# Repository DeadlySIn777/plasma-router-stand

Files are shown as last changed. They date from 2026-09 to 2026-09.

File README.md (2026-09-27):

# Plasma / router CNC stand

Public working design for **800 mm X / 1000 mm Y / 100 mm Z nominal travel**.

**Preserved baseline: Rev I.** It adds a floating/breakaway head mechanism,
stronger storage restraints, supported plumbing and defined water/tool control
circuits. It is still an engineering design with open measured interfaces and
integration work, **not a fabrication-ready or operational machine**.

**Latest design work:** [retractable ATC mechanisms for both machines](variants/retractable-atc/README.md),
with 200 mm slide travel, automatic pin release and onboard Kraken drive
allocations. The small-machine proposal includes a longer Z configuration;
the 4x8 uses a separate side bay. These have their own CAD, controls model and
checks. Exact magazine interfaces and machine qualification remain open.
Use the [variant index](variants/README.md) to distinguish these proposals from
the preserved Rev I baseline and earlier fixed-dock studies.

## Open the current design

- [Latest small and 4x8 retractable ATC work](variants/retractable-atc/README.md)
- [Baseline Rev I CAD package and limitations](output/release-review/RevI-CAD/README.md)
- [Baseline router assembly STEP](output/release-review/RevI-CAD/step/RevI_ROUTER.step)
- [Baseline bed stored assembly STEP](output/release-review/RevI-CAD/step/RevI_BED_STORED.step)
- [Plasma head hardware STEP](output/release-review/RevI-CAD/step/RevI_PLASMA_HARDWARE.step) — measured torch not yet installed
- [Updated concept PDF](output/pdf/plasma-router-stand-concept.pdf)
- [Changes, evidence and reproduction](output/design-finish-2026-09-26/README.md)
- [Current verification index](output/design-finish-2026-09-26/ACCEPTANCE.md)
- [Every original audit finding](output/design-finish-2026-09-26/FINDING-DISPOSITION.md)
- [Remaining engineering and measured inputs](output/design-finish-2026-09-26/OPEN-ITEMS.md)
- [Mechanical component schedule](output/release-review/RevI-CAD/cutlist.csv)
- [Selected controls schedule](output/design-finish-2026-09-26/controls/selected-components.json)
- [Scrap tube lengths and inspection inputs](output/design-completion-2026-09-26/SCRAP-TUBE-GUIDE.md)
- [X/Y lead check and arrival measurements](output/design-completion-2026-09-26/CONTROL-SCALE-CHECK.md)

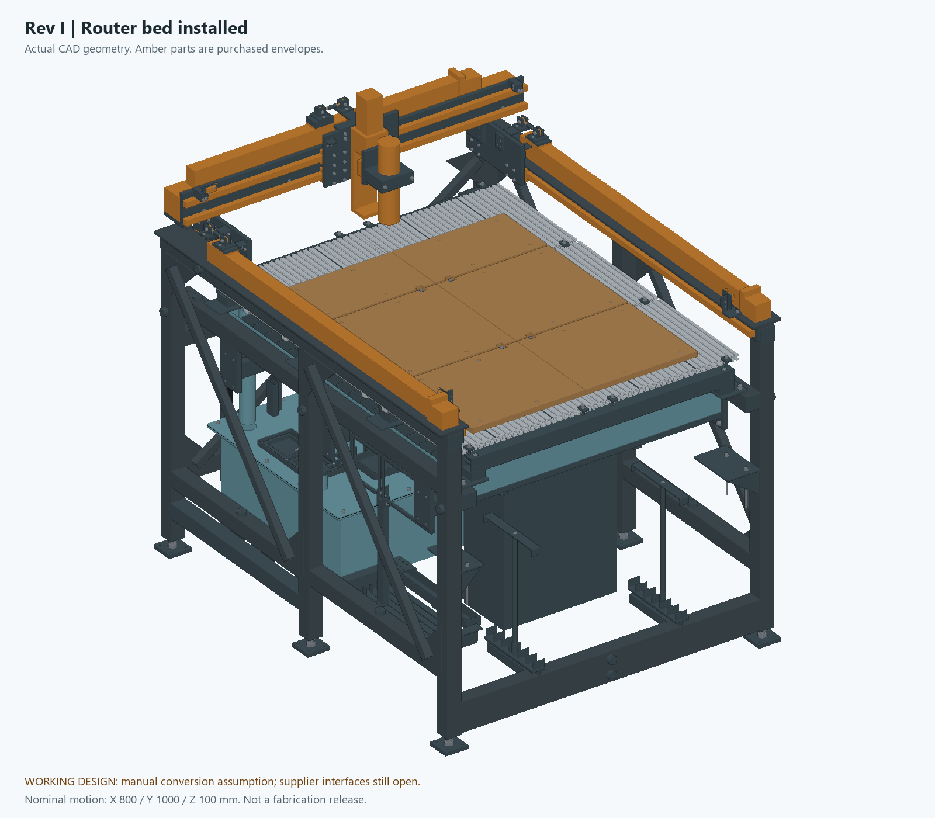
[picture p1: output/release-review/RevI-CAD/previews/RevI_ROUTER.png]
Preserved Rev I router baseline


The view above is the Rev I baseline. The [latest retractable ATC package](variants/retractable-atc/README.md) contains the new small and full-sheet machine views and STEP files.

## Design and changes

Ten 1220 mm extrusion bars yield thirty 397 mm strips in six 500 × 397 mm
panels. The bare bed is 1003 × 1211 mm. Panels, four support beams and separate
spoilboards store inside the chassis. Conversion is manual and retains 52
primary release fasteners plus restraint/tool operations. It is not an
automatic or quick bed changer.

The head now has twin guides, 6 mm captured float, cone/V/flat magnetic release,
sealed detection switches, machined clamp features and internal parking. Its
replaceable insert remains unbored until the actual torch is measured. The
plasma hardware view is therefore a mechanism assembly, not an invented
ready-to-cut VIV ARC CUT-50 setup.

Storage rods increase from 10 to 14 mm with 40 mm sockets and thicker seats.
Actual-section calculations replace the earlier incomplete stiffness claim.
The proposed light-routing target is 0.20 mm tool-to-work displacement at
100 N; known bed members alone account for about 0.135 mm. Actual motion,
mount, joint and tool compliance remain unqualified. Sand receives no
elastic-stiffness credit.

The water system gains a supported drain/flange, removable tail and parking
cup, strainer carrier, corrected pump orientation and supported pressure and
suction hose routes. The reservoir stays vented. A compressor or venturi is
not connected to the fabricated tank.

[Current controls](output/design-finish-2026-09-26/controls/README.md) retain
Kraken V1.1 with onboard drivers. Actual terminal circuits, timer contacts,
isolated run request, restart prevention and a selected C41S speed converter
are defined. Separate [isolated head inputs](output/design-finish-2026-09-26/controls/HEAD-INTERFACE.md)
connect the float and breakaway switches. Router Z zero remains manual; the
parked plasma float is not a spindle touchplate. The populated panel, complete stop/power/brake system, actual
VFD/cutter interface and physical commissioning remain unfinished.

The selected X/Y catalog variants specify **10 mm lead**, meaning movement
per screw revolution, not screw diameter. The selected SFU1605 Z has 5 mm
lead. Verify delivered modules before final calibration and adapter drilling.

The 2 × 2 tube list remains 30 blanks totaling 29,472 mm / 96.69 ft net, using
3.048 mm modeled wall. Actual scrap lengths, remaining wall and condition
must be recorded before nesting. The mechanical cut list is not a complete
electrical BOM or a current delivered purchase total.

## Evidence, history and cost

The [verification index](output/design-finish-2026-09-26/ACCEPTANCE.md) binds
current assembly, pose, route, service, mechanism, circuit and export reports
to their source files. These checks have explicit limits: nominal clear
geometry does not establish physical rigidity, force thresholds, operator
access, live electrical behavior or machining accuracy.

The active generator is [build_revi.py](output/release-review/RevE-ENGINEERING/build_revi.py).
Shared Python sources retain their legacy directory name; **current exports
are in RevI-CAD**. Rev H, Rev G, older exports and the
[29-finding audit](output/cad-reaudit-2026-09-25/README.md) are preserved as
historical evidence. They are not relabeled as current results.

[Earlier prices](outputs/reve-30510/CNC-plasma-RevE-budget.xlsx) and the
[actual-price audit](outputs/reve-30510/actual-cost/REAL-COST.md) are historical
procurement research. Quantities changed; neither is a complete Rev I build
total. No purchase, vendor message, firmware flash or machine operation is
implied by this public design record.

CadQuery/OpenCascade generate exchange geometry; ReportLab generates the
concept brief. This is not a native Fusion feature-history or machine-specific
CAM release. The [original snapshot manifest](REPOSITORY-SNAPSHOT.json)
describes the initial import only. Supplier material retains its existing
license notices; this repository grants no new rights over it.

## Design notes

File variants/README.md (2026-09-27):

# Small ATC and full-sheet 4x8 variants

Two development variants extend the [existing Rev I small machine](../output/release-review/RevI-CAD/README.md).
The requested ATC, repeatable removable table interfaces and second full-sheet
machine are now separate design work. Rev I remains the small-machine baseline;
its existing checks do not automatically qualify these additions.

| Design | Working area / stock | Bed and ATC arrangement |
|---|---|---|
| [Small retractable ATC](retractable-atc/small-mechanism/README.md) | Targets existing 800 X × 1000 Y; proposed 200 Z configuration, separately from baseline 100 Z | Raised open carrier, guided rearward parking, automatic spring-pin release; exact loaded magazine remains to fit |
| [Full-sheet retractable ATC](retractable-atc/large-mechanism/README.md) | 1219.2 × 2438.4 mm stock; additional deck-surfacing travel | Separate dry side bay, 200 mm slide and guided outer shutter; based on the [4x8 development frame](48x96/README.md) |
| [Shared locating interfaces](common/location/README.md) | Metal datum chain, independently checked fits and thermal allowances | Round pin + diamond pin, replaceable metal bushings, hard Z seats and separate clamps |

**Latest package:** [retractable ATC on both machines](retractable-atc/README.md),
with a 200 mm useful-stroke target, detailed mechanism candidates and an offline
interlock model. The earlier [fixed small dock](small-atc/README.md) and first
packaging studies remain historical candidates. They are not the newest ATC
assembly and do not share the revised clearance result.

The large dimensions assume 4x8 means usable sheet size. ATC on both machines is
now requested; the exact kit remains unconfirmed. The [requirements record](requirements.json) distinguishes requests,
working assumptions and open inputs.

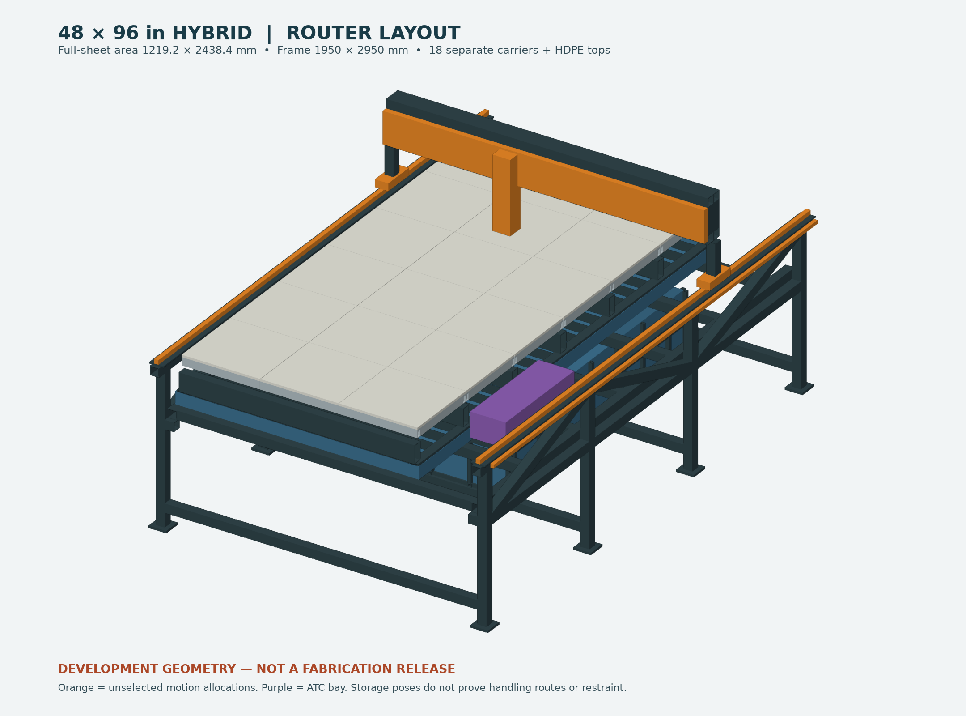
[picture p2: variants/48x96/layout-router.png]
Full-sheet machine development layout


The image above shows the underlying 4x8 frame layout. Current ATC mechanism
views and exchange files are linked from the latest package.

## Repeatable removal

Locate each metal carrier with one round pin and one relieved/diamond pin.
The first fixes two horizontal directions; the second fixes rotation without
forcing a second fully constrained hole spacing. Three hard seats define the
height plane. Supplementary supports must be fitted to that plane, and separate
clamps provide hold-down. Precision pins are not pressed into HDPE.

The HDPE top is a wear layer attached with room for thermal movement and metal
compression limiters. Its expansion must not move the carrier's locating
features. Each reinstallation requires clean datums, correct seating, clamping
and a reference check. Numerical return targets in the common interface are
acceptance targets, not demonstrated machine accuracy.

The common locator assembly is modeled separately. Its integration into the
small table and all 18 large carriers remains open; the table models do not yet
contain the completed pin, clamp and thermal-clearance details.

## ATC is more than a magazine

The [retractable mechanism controls](retractable-atc/controls/README.md) extend
the earlier [ATC interface reservations](common/controls/ATC-INTEGRATION.md)
with motor allocations, isolated position inputs, lock outputs and an executable
offline interlock model. This is not flashed machine firmware or calibrated M6.
The actual spindle/VFD must still support the required low-speed reverse cycle.

Manufacturer mounting geometry and the exact RapidChange kit are still required
to release the drilled adapter and pocket coordinates. Colored ATC allocations
in CAD represent reserved space, not a supplier-certified magazine solid.
The earlier fixed small dock consumes part of its work area. Its retractable
successor adds vertical clearance and explicit stored-tool limits to address
that loss; the large machine reserves a side bay beyond the sheet. Removal must preserve or re-establish
the pocket reference before automatic changes resume.

The approximately **USD 700** kit figure is a user budget target. Official shop
pages currently present different prices/options. It is not a delivered quote
and excludes any unquoted freight, tax, extra tooling and interface parts.
The [kit comparison and manufacturer requirements](common/atc/README.md) record
the sourced prices and the exact dimensions that still need confirmation.

## Scope of this package

The links above include generated CAD, checks and explicit limits. The large
machine is a layout with unselected motion components and unfinished joint,
service and conversion details. The small dock is a candidate that requires the
actual kit and spindle dimensions. Neither is a fabrication or CAM release.

The existing [Rev I concept PDF](../output/pdf/plasma-router-stand-concept.pdf)
continues to describe the baseline small machine. It is not silently relabeled
as the new 4x8 or an ATC-qualified model. See the variant pages for new geometry.

The [package check](package-verification.json) binds the new reports and files
to their source and checks that the prior baseline remains unchanged. A PASS
there concerns the published evidence, not fabrication or machine operation.

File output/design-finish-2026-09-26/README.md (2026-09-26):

# Rev I design repairs — 26 September 2026

Rev I adds a guided floating/breakaway head, stronger storage restraints,
supported plumbing with service paths, and defined water/tool control circuits
to the frozen Rev H design. It is a working engineering package, **not a
finished fabrication or operating-machine release**.

The current [verification index](ACCEPTANCE.md) identifies the source-matching
reports. An intermediate report marked failed or stale is diagnostic history,
not acceptance. Read the index before using counts or pass claims below.

## Current design

- [CAD package](../release-review/RevI-CAD/README.md), including router, stored-bed and plasma-head-hardware assemblies.
- [Updated concept PDF](../pdf/plasma-router-stand-concept.pdf).
- [Original findings and current disposition](FINDING-DISPOSITION.md).
- [Remaining engineering and measured inputs](OPEN-ITEMS.md).
- [Structural joints and load targets](structure/JOINTS.md).
- [Head mechanism, transfer sequence and limitations](motion/README.md).
- [Combined bed and tool conversion sequence](motion/CONVERSION-SEQUENCE.md).
- [Water/cabinet geometry and servicing](service/README.md).
- [Kraken control baseline and terminal circuits](controls/README.md).
- [Isolated float-probe and breakaway interfaces](controls/HEAD-INTERFACE.md).
- [Current part inventory and material layouts](../release-review/RevI-CAD/cutlist.csv).
- [Arrival measurement worksheet](../design-completion-2026-09-26/motion/ARRIVAL-MEASUREMENTS.md) and [scrap tube guide](../design-completion-2026-09-26/SCRAP-TUBE-GUIDE.md).

## Changes and their purpose

| Area | Corrected definition | Remaining physical limit |
|---|---|---|
| Head mechanism | Twin guides, captured 6 mm float, cone/V/flat magnetic release, switch cams, machined clamp halves and internal parking | Actual torch bore/nozzle, cable and tether, probing/release forces and tilted separation remain unqualified |
| Storage restraints | Ø14 rods, 40 mm sockets, thicker seats, defined engagement and revised transfer heights | These contain stored parts; they are not rated lifting hardware |
| Bed rigidity and joints | Actual extrusion section, member/joint calculations, explicit force targets and slot-lip coupon procedure | Purchased motion compliance and full tool-to-work stiffness cannot be inferred from isolated beams |
| Drain and filter service | Supported reducer/flange, removable tail with parking cup, removable strainer bridges and supported hoses | Actual purchased port makeup and end-fitting stacks require receipt fit and wet testing |
| Cabinet | Correct 500 × 400 × 200 mm nominal body, backplate, gland covers and drilled supports | Purchased hinge/lock/standoffs and a complete populated/thermal panel remain unfinished |
| Controls | Actual relay poles/terminals, timed water circuit, isolated run request, release-to-rearm behavior and selected speed conversion | Hardware stop/power/brake integration and the identified cutter interface remain separate unfinished work |

The manual conversion keeps the six panels, four beams, separate spoilboards
and storage hardware inside the chassis. It retains 52 primary release
fasteners plus restraint/tool operations; it is not an automatic or quick bed
changer. The structure and head reports define the additional handling steps.

The bare deck is 1003 × 1211 mm. Ten 1220 mm extrusion bars supply thirty
397 mm pieces: five two-packs, not five individual bars. Six separate
spoilboards sit within the nominal router center envelope. Cutting access
still depends on the actual tool, guards and clamping.

X/Y catalog lead remains **10 mm per screw revolution**; Z is specified as
SFU1605 / 5 mm lead. Travel, screw diameter and lead are different dimensions.
The arriving modules still need measured mating datums before adapter holes
can become manufacturing definitions.

The 2 × 2 tube list remains 30 blanks, 29,472 mm / 96.69 ft net. The model uses
3.048 mm wall. Random scrap requires its own sound-length nest and wall/condition
record. Sand adds stationary mass; no calculation credits it with elastic
stiffness. Owned aluminum quantity and alloy remain unverified.

## How to reproduce the current evidence

CAD uses CadQuery 2.7/OpenCascade and ezdxf. From the repository root:

```text
python output/release-review/RevE-ENGINEERING/build_revi.py
python output/design-finish-2026-09-26/verify_revi.py
python output/design-finish-2026-09-26/verify_revi.py --steps-only
python output/design-finish-2026-09-26/verify_revi_routes.py
python output/design-finish-2026-09-26/structure/calculate_structure.py --integrated
python output/design-finish-2026-09-26/structure/check_reinforced_paths.py --integrated
python output/design-finish-2026-09-26/structure/check_temp_fixture_transfer.py --integrated
python output/design-finish-2026-09-26/service/verify_service_finish.py --builder build_revi
python output/design-finish-2026-09-26/motion/verify_motion_finish.py
python output/design-finish-2026-09-26/motion/verify_motion_finish.py --integrated --builder build_revi
python output/design-finish-2026-09-26/motion/verify_head_package.py
python output/design-finish-2026-09-26/motion/check_transfer_staging.py
python output/design-finish-2026-09-26/motion/check_router_transfer.py
python output/design-finish-2026-09-26/motion/check_conversion_prerequisites.py
python output/design-finish-2026-09-26/controls/verify_circuit.py
python output/design-finish-2026-09-26/controls/verify_run_interface.py
python output/design-finish-2026-09-26/controls/verify_head_interface.py
python package_revi.py
python output/release-review/RevE-ENGINEERING/render_revi.py
python output/design-finish-2026-09-26/render_head_detail.py
python build_concept_revi.py
python output/design-finish-2026-09-26/final_acceptance.py
```

Do not change source files during these runs. Each report binds its actual
inputs; an old pass does not qualify a modified part. Rendering needs NumPy,
Pillow and the repository renderer; the PDF additionally needs ReportLab,
pypdf and the recorded Windows fonts. Review the rendered PDF before copying
it to the stable concept path. This documents the local build, not a certified
clean-machine environment or native Fusion feature history.

Previous audits, revisions and cost workbooks are preserved as history.
Earlier quantities and prices are not a delivered Rev I build total. No
manufacturing G-code, purchase, supplier message, controller flash, live motion
or cutting operation is part of this revision.

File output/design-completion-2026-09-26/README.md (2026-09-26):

# Rev H completion work - 26 September 2026

This revision makes concrete changes to the bed, water service and motion definitions. **It does not finish the entire machine.** The remaining items include actual purchased mating dimensions, a complete plasma head, full rigidity/load qualification and electrical/plumbing integration.

## Current artifacts

- [Rev H CAD package](../release-review/RevH-CAD/README.md)
- [Concept PDF](../pdf/plasma-router-stand-concept.pdf)
- [Scrap tube shopping guide](SCRAP-TUBE-GUIDE.md)
- [Confirmed owner inputs](USER-INPUTS.md)
- [X/Y lead and controller scale check](CONTROL-SCALE-CHECK.md)
- [Motion order/interface decisions](motion/ORDER-AND-INTERFACES.md) and [arrival measurement record](motion/ARRIVAL-MEASUREMENTS.md)
- [Bed changes and handling instructions](bed/README.md)
- [Water changes and exact service scope](water/README.md)

## What changed

| Area | Concrete Rev H change | Remaining limitation |
|---|---|---|
| Bed top-slot nuts | Twelve retained strips replace 24 loose nuts | Actual extrusion fit, thread engagement and controlled preload need qualification |
| Stored beams | Four through-bolts and eight welded compression sleeves tie the beam stacks to their shelves | Restraint/weld/rack load capacity and actual access are unqualified |
| Panel/spoilboard storage | Removable panel retainers and an indexed folding spoilboard guard | Follow the phase-specific conversion sequence; physical fit and handling still need demonstration |
| Temporary beam parking | Two boxed keepers locate the first beam on the second during front-seat work | Contains the nominal stack; not a rated lifting fixture |
| Reservoir access | Two service hatches, seals, fasteners, cover parking and a real washout closure | Full cleaning reach, loose-fastener handling and wet testing remain |
| Refill path | Defined fabricated spout, pan penetration and support; 30 mm nominal air gap | Pump/valve ports, adapters, supported hoses and actual clearance remain unresolved |
| Z adapter | Known tool-side holes retained; fictitious output slots removed | Output height, four-hole pattern, thread/depth and attachment capacity remain unverified |
| Z power-off holding | A sourced braked-motor candidate is reserved and statically screened | Coupling/flange fit, dynamic response and complete load-path qualification remain open |

The selected X and Y catalog variants both specify **10 mm lead**. The user has ordered Y; X and Z are planned for Monday. The exact catalog checks do not inspect the order or delivered hardware. Firmware's existing X/Y scale calculation already uses 10 mm lead; no firmware was changed or flashed.

## Verification records

- [Combined evidence acceptance index](ACCEPTANCE.md)
- [Integrated assemblies, shared parts and nine router poses](verification.json)
- [Independent final STEP readback](step-verification.json)
- [Export inventory and material-layout verification](package-verification.json)
- [Integrated hatch and washout service paths](water/integrated-verification.json)
- Bed route and restraint evidence is linked from the bed report; original Rev G proofs are retained as historical records.

The final source-matching verification index passes. Both assemblies contain 1,448 valid solids with zero unresolved intersections; all nine checked router poses pass. The continuous proofs include 121 original board/panel/beam segments, 86 added restraint segments, 20 temporary-keeper transfer segments and 10 water-service segments. The two final keeper insertion segments repeat checks in the restraint report. Both final STEP files were independently reimported and matched to their recorded hashes, counts and volumes.

The export inventory contains 331 part numbers, 242 unguarded individual STEP files and 134 flat DXFs, with no missing or stale individual files. Nominal dry panel mass is approximately 4.00 kg each including retained strips and screws, excluding separate spoilboards and work; weigh actual panels. The four-page concept PDF was rendered and all pages visually reviewed.

Read each report's `status`, source hashes and scope. Static clearances are nominal. Continuous handling checks cover the stated solids and preconditions; they do not model the operator, flexible leads, manufacturing error or structural deformation. Valid files and clear paths do not establish a safe or accurate cutting machine.

## What still prevents a finished CAD/CAM handoff

1. Measure the arriving Y interfaces and obtain or measure the selected Z output interface. The current source identifies each required datum; the adapter stays guarded until those values exist.
2. Measure the owned torch and identify the exact VIV ARC CUT-50 version/interface. Its floating touch-off, breakaway and lead routing are still unfinished. A generic AG-60 product picture cannot finish this geometry or wiring.
3. Establish actual scrap lengths, remaining wall/condition and usable aluminum inventory. Qualify the complete frame-to-tool-to-bed load path and repeat installation behavior; sand adds mass, not elastic stiffness.
4. Finish purchased plumbing fit, hose support, cable chains/way covers, enclosure door/thermal layout, wiring and physical interlock/brake tests.

The 2 x 2 tube schedule remains 30 blanks, 29,472 mm net. Actual scrap prices and yields are not yet known. Historical cost workbooks are not a current delivered build total. The public repository contains review work, not an instruction to order every listed item or execute every DXF as a through cut.

No vendor messages, purchases, controller flashing or machine operation occurred in this work. The old 29-finding audit remains unchanged; these new artifacts do not retrospectively relabel its findings as closed.

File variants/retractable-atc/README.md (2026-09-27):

# Retractable ATC — small and full-sheet machines

The latest revision develops the requested **200 mm magazine travel on both machines** into separate mechanical assemblies, sourced drive interfaces, automatic locking arrangements and an executable control sequence. Use the two mechanism pages below for current CAD. The earlier `small-study` and `large-study` folders preserve the first packaging studies; they are not the current assemblies.

**Status: engineering development, not a fabrication/CAM release or an operating ATC.** Exact magazine geometry, the small machine's proposed longer Z, actual spindle/VFD behavior and physical qualification still determine whether the installation can work as modeled. The preserved Rev I machine has not silently acquired those capabilities.

| Machine | Current arrangement | Design constraint |
|---|---|---|
| [Small machine: CAD, drawings and checks](small-mechanism/README.md) | Rear tray moves 200 mm in Y on two 350 mm rails; raised, open carrier gives stored cutters space below the magazine | Targets the nominal 800 × 1000 mm work rectangle with a working 50 mm combined stock/clamp height. Requires the proposed longer Z configuration; the original Z remains 100 mm. |
| [Full-sheet 4x8: CAD, drawings and checks](large-mechanism/README.md) | Magazine moves 200 mm across a separate side bay; removable adapter strips sit above a guided carrier | Keeps the nominal 1219.2 × 2438.4 mm sheet area separate from the magazine. Deck surfacing and head access still depend on the defined parked pose. |

The magazine is located and held by the mechanism at each endpoint. Its drive screw is not the precision stop or the only means of restraint. Spring-engaged guided pins have separate release actuators and feedback from the pins themselves. The fabricated carrier and its replaceable magazine mounting plates are distinct parts; vendor mounting holes and pocket coordinates remain undrilled and uncalibrated until the exact kit is identified.

## Current CAD views

These previews are rendered from the delivered STEP assemblies. Purple geometry identifies an unverified supplier allocation or proposed motion package; it is not a purchased-part drawing.

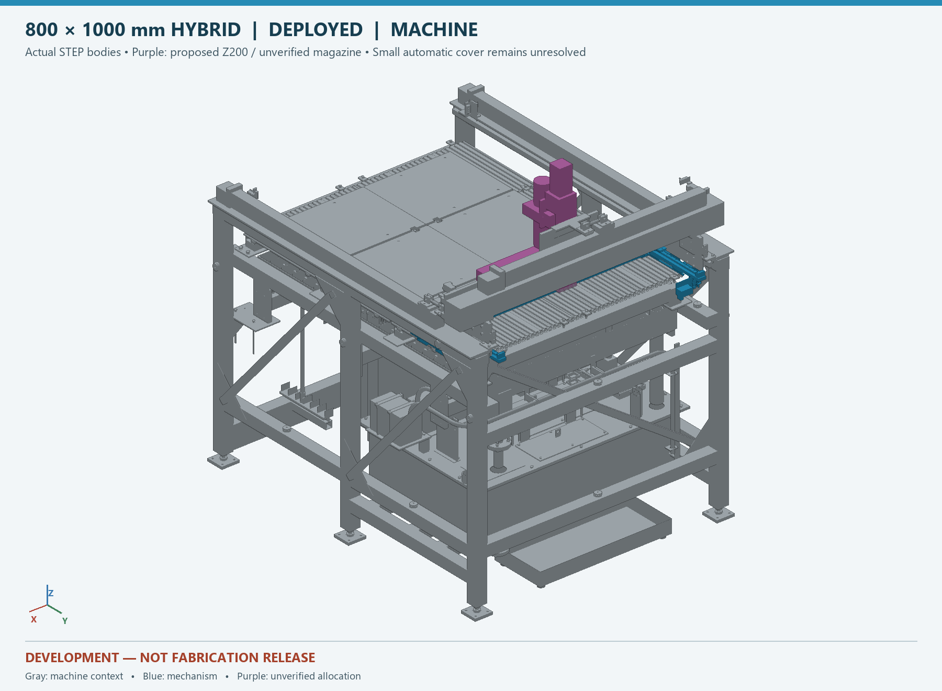
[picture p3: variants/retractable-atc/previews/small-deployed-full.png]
Small machine with the retractable carrier deployed


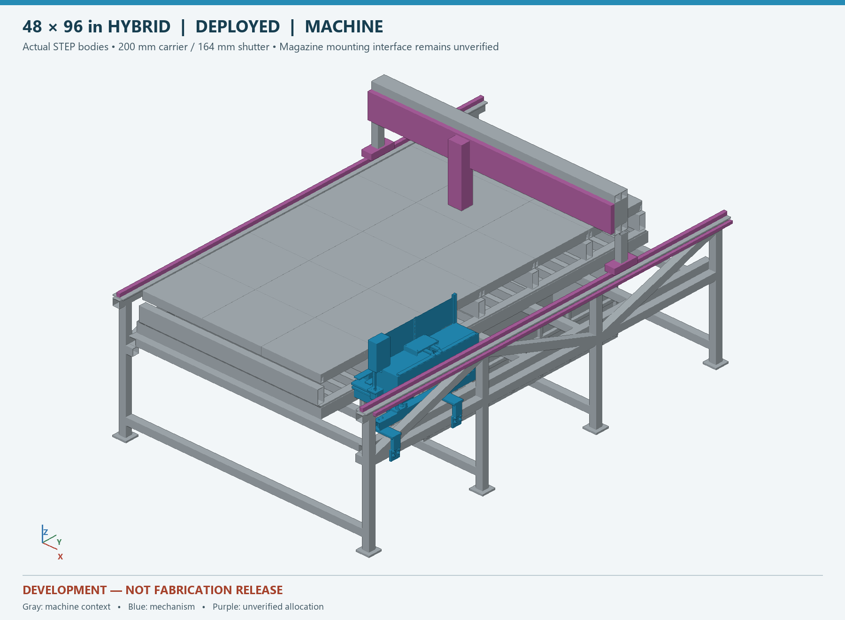
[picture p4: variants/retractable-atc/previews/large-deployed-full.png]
Full-sheet machine with the retractable carrier deployed


The mechanism pages also show the parked states and closer views. [Preview verification](preview-verification.json) binds the images to their STEP files.

## Guides, drives and covers

The proposed guides use the sourced **HIWIN MGN12H/MGNR12** mounting geometry: two 350 mm rails and four blocks per slide. A 200 mm rail is too short for 200 mm motion with two separated blocks. The bounding calculation is `200 + 80 + 45.8 + 10 + 10 = 345.8 mm`; [the checked arithmetic](guide-stroke-check.json) uses the maximum published block length. These catalog dimensions do not give an inexpensive clone HIWIN load ratings.

The drive candidate is a **STEPPERONLINE 17E19S1684MB4-300RS**, with an integrated 300 mm TR8×8 screw. Its 8 mm lead is for the new magazine/shutter drives, not a change to the original X/Y axis lead. [Sourced dimensions](hardware/source-data.json) distinguish the current model, published alias and unverified delivered details. Holding torque alone does not establish running thrust or a brake function.

The locking arrangement uses separate [Delta release solenoids](hardware/LOCK-ACTUATOR.md) and [noncontact pin sensors](hardware/PIN-SENSORS.md). The guided pin and housing carry the lock reaction. A light return spring, actual friction, hot-coil pull and release timing require measured qualification. Sensor electronics cannot prove that a blocked optical slot contains the intended pin flag.

The large machine has a separate powered outer shutter and dust enclosure. The small machine currently has the carrier and locks only: its constrained rear corridor does not establish room for that same shutter. Its cover arrangement remains a specific unfinished interface, and its automatic profile must remain disabled. Neither arrangement is qualified as a plasma spark or fire barrier. **The new control candidate denies plasma permission**, including when the magazine is parked. Plasma conversion requires a qualified protected arrangement or a separately verified removal/configuration workflow.

## Control sequence and onboard drivers

The [controls package](controls/README.md) defines Kraken S5 for the magazine slide and S6 for the large machine's outer shutter, with isolated field inputs and separate lock outputs. The small machine has no assigned outer-shutter travel or completed automatic profile. The design retains the user's preference for onboard stepper drivers. S5/S6 use the documented 75 mΩ current-sense value; their settings cannot be copied blindly from Kraken V1.1 S1–S4.

The [terminal/circuit definition](controls/WIRING.md) and [I/O allocation](controls/io_plan.json) specify the added interfaces. The existing hardware stop and tool-power permission remain independent. The new relay contact belongs in series with the existing run-arm path, without a bypass. VFD and kit feedback channels remain open interfaces until their actual electrical signals and meanings are known.

The offline sequence stops the spindle, confirms a current clearance pose, opens and captures the shutter, releases both magazine pins, deploys, confirms the matching endpoint and lock, and only then permits the calibrated tool operation. It requires another verified clearance pose before retracting and reclosing, then confirms the shutter's closed retaining pin before restoring router permission. Invalid feedback, missing endpoints, stale data and interrupted cycles inhibit permission and require deliberate recovery.

This package contains **no flashed firmware, functioning M6 integration or calibrated pocket coordinates**. Its default configuration does not energize hardware. Simulation and source checks demonstrate the specified behavior only; they do not qualify a populated control cabinet or an energized machine.

## Evidence and fabrication boundary

The small machine's bed-removal sequence was revised around the installed rear guides. Its checks cover 42 panel, 60 spoilboard and 31 beam movements within the modeled frame footprint. Conversion remains manual, with defined tool/fastener/restraint preconditions; these checks do not include the operator's hands or flexible leads.

- [Small mechanism verification](small-mechanism/verification.json) and [large mechanism verification](large-mechanism/verification.json) bind their specific modeled checks to the sources and exported artifacts.
- [Control verification](controls/verification.json) records the offline sequence and fault checks.
- [Independent export verification](export-verification.json) reopens STEP/DXF files without importing the geometry generators. It checks valid positive-volume solids, millimetre drawing units, file structure and circular feature correspondence between each drawing and its part. It does not establish assembly clearance, complete machining setups or rigidity.
- [Publication verification](../package-verification.json) checks source/artifact hashes, local document links and the unchanged Rev I baseline.

Remaining release inputs are concrete: the selected RapidChange kit's dimensions and mounting pattern; loaded tool/nut geometry; the proposed small Z module's drawing and retained-load behavior; actual spindle low-speed forward/reverse performance; measured alignment, loaded deflection and pin repeatability; and tested electrical/firmware integration. The mechanism pages identify any additional CAD findings and incomplete fabrication details. The 4x8's purchased main motion, structural joints and complete bed conversion also remain separate development work.

The working 50 mm stock/clamp height is an assumption, not a confirmed user limit. Clearance must be checked against the actual tallest clamp and longest stored cutter. A blank supplier interface in a STEP file is not permission to guess the drilling pattern.

The approximately **$700 ATC kit target** excludes unquoted installation hardware, freight, taxes and tooling. Component source records distinguish observed goods prices from missing delivered quotes. No complete build total is asserted by this revision.

Primary references: [RapidChange requirements](https://rapidchangeatc.com/faq/), [HIWIN guide catalog](https://www.hiwin.com/wp-content/uploads/HIWIN-Linear-Guideway-Catalog.pdf#page=91), [BTT Kraken documentation](https://global.bttwiki.com/Kraken.html). The [requirements record](../requirements.json) separates confirmed requests from assumptions and unresolved interfaces.

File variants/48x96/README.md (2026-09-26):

# Full-sheet 48 × 96 in hybrid — development layout

This is a separate, parametric development variant for a **1219.2 × 2438.4 mm usable sheet**, with the long direction along Y. That interpretation of “4 × 8” remains an explicit assumption. The model has a fabricated frame, wet pan, removable aluminum carriers, separate HDPE wear panels and space for a right-side RapidChange magazine. It is **not ready for fabrication or parts ordering**: purchased motion, docking hardware integration and the physical conversion sequence remain unfinished. Frozen Rev I files are not imported or changed.

Open [router STEP](router.step), [plasma/storage STEP](plasma_layout.step), or the [dimensioned plan](layout-plan.svg). [Router preview](layout-router.png) and [plasma preview](layout-plasma.png) are rendered directly from the CAD using a per-pixel depth buffer. Orange bodies are unselected motion allocations; purple is an ATC space allocation, not a verified product body.

## Dimensions and reach

| Item | Current dimension / position |
|---|---|
| Overall frame, including feet | 1950 × 2950 mm; eight legs |
| Usable sheet | 1219.2 × 2438.4 mm, starting at X180 / Y230 |
| Router deck | 1320 × 2550 mm, starting at X130 / Y175 |
| Removable modules | 3 columns × 6 rows; 18 carriers and 18 independent HDPE tops |
| Each panel | 438.667 × 423.333 mm; 2 mm gaps |
| Carrier construction | 38.1 × 25.4 × 3.175 mm aluminum RHS, two internal ribs, 6.35 mm backing plate |
| HDPE wear top | 12.7 mm; finished top Z912.7 |
| Grid / carrier / wear-top planes | Z829.55 / Z855.55 / Z912.7 |
| Grid-to-wear-top allocation | 83.15 mm = 26 mm docking interval + 38.1 mm frame + 6.35 mm backing + 12.7 mm HDPE |
| Full-deck surfacing tool-center bounds | X117.3–1462.7, Y162.3–2737.7, for a 12.7 mm cutter radius |
| Total X tool-center allocation including ATC | X117.3–1800; magazine center X1700 |
| X axis body allocation | X75–1875, including an assumed 80 mm carriage width |
| Y gantry allowance | Tool-to-gantry offset 100 mm; carriage half-length 90 mm; both travel extremes stay inside the frame |
| Wet pan inside | 1360 × 2590 mm; 2 mm sheet; floor underside Z650 |
| Water / slat planes | 50 mm nominal water depth, water Z702, slat tops Z710 |
| Vented reservoir | 450 × 1500 × 400 mm internal; 270 L gross / 230 L working allocation |
| Dry ATC bay | 600 × 200 mm in plan at X1600–1800 / Y400–1000 |

Full-sheet coverage and full-deck surfacing are different requirements; this allocation provides the latter as well as the former. Those arithmetic bounds do not establish real end-stop clearance, drive mounting, spindle reach, gantry collision clearance or ATC tool-length capacity. The smaller machine’s 800 / 1000 mm modules and 100 mm Z are not being silently stretched into this design.

## Frame, removable bed and storage

The main frame uses nominal 2 × 2 × 0.120 in steel tube, eight legs and deep side trusses. Actual junkyard tube wall, grade, corrosion, straightness and usable lengths must replace the nominal assumptions before a fabrication cut list is issued. Rail preparation strips are 8 mm machining/welding allowances, with no guessed rail holes.

The seven removable transverse grid beams use **4 × 2 × 0.120 in RHS on edge**. This is a stock alternative for the grid, not a requirement to replace all salvaged 2 × 2 chassis tube. Compared with two parallel 2 × 2 members per beam, the seven beams fall from 84.46 to 64.69 kg. Under an illustrative 500 N central load across a 1320 mm ideal simple span, elastic deflection falls from 0.270 to 0.100 mm; section stiffness increases by 2.69 times. These calculations do not qualify welds, connections, local walls, gantry stiffness or the complete tool-to-work load path. Stacking two tubes vertically cannot receive equivalent composite stiffness credit without a designed shear connection.

Each aluminum carrier is about **5.53 kg**, and each independent HDPE top about **2.24 kg**, before docking and clamp hardware. Splitting the bed avoids a single large aluminum/HDPE assembly. The [common locating interface](../common/location/README.md) provides a representative round/diamond pin concept and support cartridges; it is **not integrated into all 18 carriers here**. The reserved 26 mm lower interface keeps unnotched carrier tube above the upper receiver blocks. Pin projection above that plane still requires a properly machined carrier pocket. Clamp seats, attachment holes, HDPE expansion clearances and all actual locator loads remain open.

The plasma STEP places all 18 aluminum carriers, all 18 wear tops and all seven grid beams in separate poses inside the 1950 × 2950 mm plan footprint. **These are allocated storage poses, not supported storage racks.** Retention, spark shielding, handles, insertion paths and the complete manual conversion order have not been modeled or proved. The arrangement must not be treated as an instruction to leave parts unsupported. Its current purpose is to expose the volume that real racks and handling paths must fit.

## Water and mass tradeoff

The pan holds **176.12 L** at the nominal 50 mm depth. The reservoir working allocation leaves **53.88 L** beyond that volume for wet lines, heel/sludge and operational reserve. It stays vented; this layout does not qualify a pressure fill/drain scheme, pump, valve, hose route or automatic drain timing.

Pan and tank sheet were reduced from a heavy 3.048 mm first pass to 2 mm, with explicit pan bearers and a 225 mm tank stiffener grid. A simple one-way elastic strip screen gives approximately 1.56 mm pan deflection and 16.61 MPa bending stress at 50 mm water head over 425 mm support pitch. A 225 mm tank wall strip at a conservative full 400 mm water head gives approximately 0.98 mm deflection. These are preliminary screens; weld restraint, distortion, corrosion allowance, global support behavior and leak testing remain to qualify.

| Nominal modeled material | First pass | Current |
|---|---:|---:|
| Seven removable grid beams | 84.46 kg | 64.69 kg |
| Pan sheet | 101.32 kg | 63.99 kg |
| Bare reservoir sheet | 58.56 kg | 35.26 kg |
| Current reservoir stiffeners | Not included | 22.83 kg |
| Rail preparation strips | 46.10 kg | 29.04 kg |
| Entire modeled dry layout | 730.28 kg | **684.59 kg** |

The overall reduction is only 45.69 kg because the revised model also adds real pan support members, grid load pads and tank stiffeners. The current reservoir assembly is roughly 58.10 kg, so thinning its sheet alone is not a large net saving. **684.59 kg remains a heavy development candidate, not a finished budget recommendation.** It excludes motion hardware, motors, reducers, fasteners, cables, weld metal, ATC tools, stock and water. Adding only the nominal pan water gives approximately 860.71 kg. Stock loads, support reactions and floor/foot design remain unqualified. No purchase price or shipping quote is implied by these calculated masses.

## Long-axis drive choice

The provisional long axis uses independently driven racks on the two sides. Long rotating screws need a speed check before selection. For illustration, the THK permissible-speed expression with a 2900 mm bearing span, 20 mm **root** diameter and fixed-supported ends gives about 359 rpm; at 10 mm lead that is only 3.59 m/min. The formula already includes its stated critical-speed factor. Root diameter is not nominal diameter, and bearing and DN limits still apply. This example supports investigating rack drive or a rotating-nut alternative; it does not prohibit every possible ball-screw system. [THK speed selection](https://www.thk.com/us/en/products/ball_screw/selection/0007/), [THK equation and end-support factors](https://tech.thk.com/en/products/pdf_download.php?file=E_15_BallScrew.pdf).

Rack sections can be joined for long travel, but mounting accuracy, mesh and backlash need an actual selected rack/pinion/reducer design. Two motors on opposite Y sides are not the same thing as a preloaded dual-pinion mechanism on one rack. A module-2, 20-tooth pinion and 3:1 reduction would move 41.89 mm per motor revolution; the modeled 25.13 m/min at 600 motor rpm is arithmetic only, not an attainable feed rating. [Atlanta rack systems](https://atlantadrives.com/racks.htm), [Atlanta preload arrangements](https://atlantadrives.com/systems1.htm).

With rail centers 1800 mm apart, a 1 mm side-to-side position mismatch implies about 0.000556 rad of small-angle yaw and about 0.677 mm difference in Y position across the full sheet width. The Y error varies across X; it does not increase merely because the gantry travels farther along Y. Dual homing switches address initial squaring; they do not by themselves detect every cutting stall or structural deflection.

## ATC and remaining interfaces

The right-side bay preserves separate dry space and tool-center reach. Exact magazine endcaps, pocket pitch, cover sweep, fasteners, spindle reversal behavior, tool projection and Z approach must come from the selected kit. The common study requests at least 90 mm approach clearance, but this layout does not prove it for a real tool stack. See [RapidChange source review](../common/atc/README.md) and [controller integration study](../common/controls/ATC-INTEGRATION.md). No manufacturer bolt pattern is invented in these STEP files.

The next design gates are selected rail/carriage/drive interfaces and capacity; complete gantry and joint stiffness; carrier docking and thermal movement details; retained storage racks and an in-footprint conversion path; real spindle/torch/ATC assemblies and clearance; supported water routing and service access; cabinet, grounding, plasma interference protection and control interlocks. Stock loading/unloading access also needs a real handling plan. The current allocation is not an energized machine or a claim of automatic mode conversion.

## Evidence and reproduction

- [Layout report](layout-verification.json): 347 valid single solids per state, STEP re-import counts/volumes, deck coverage, plan containment and named reach checks. Physical release fields are explicitly false.
- [Static report](static-verification.json): 338 fabricated solids per state, zero unexpected positive-volume intersections. Nine unselected motion/ATC allocations are excluded. The checker uses AABB broadphase and exact Boolean intersections for candidates; the cleared final geometry has zero positive-overlap broadphase candidates. This does not test handling paths or strength.
- [Preview record](preview-verification.json): source and image hashes for the technical renders. Both 3D states were visually inspected after the per-pixel depth-buffer correction; the plan labels were also checked after encoding repair.
- [Independent package verification](package-verification.json): fresh STEP imports compared with a fresh parametric build, current source/report/artifact bindings and explicit hold fields. Passing that check certifies this bounded package, not fabrication readiness.

Run `python layout.py`, `python check_static.py`, `python render.py`, then `python check_package.py` from this folder using a CadQuery-capable environment. The renderer also requires NumPy and Matplotlib. All dimensions are millimeters.

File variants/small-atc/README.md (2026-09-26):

# Small machine: removable rear ATC dock candidate

This variant preserves the original 800 × 1000 × 100 mm machine and all frozen Rev I artifacts. It adds a **reviewable frame-supported dock candidate**, not a verified RapidChange kit or finished automatic conversion. No parts have been ordered and no machine files have been flashed.

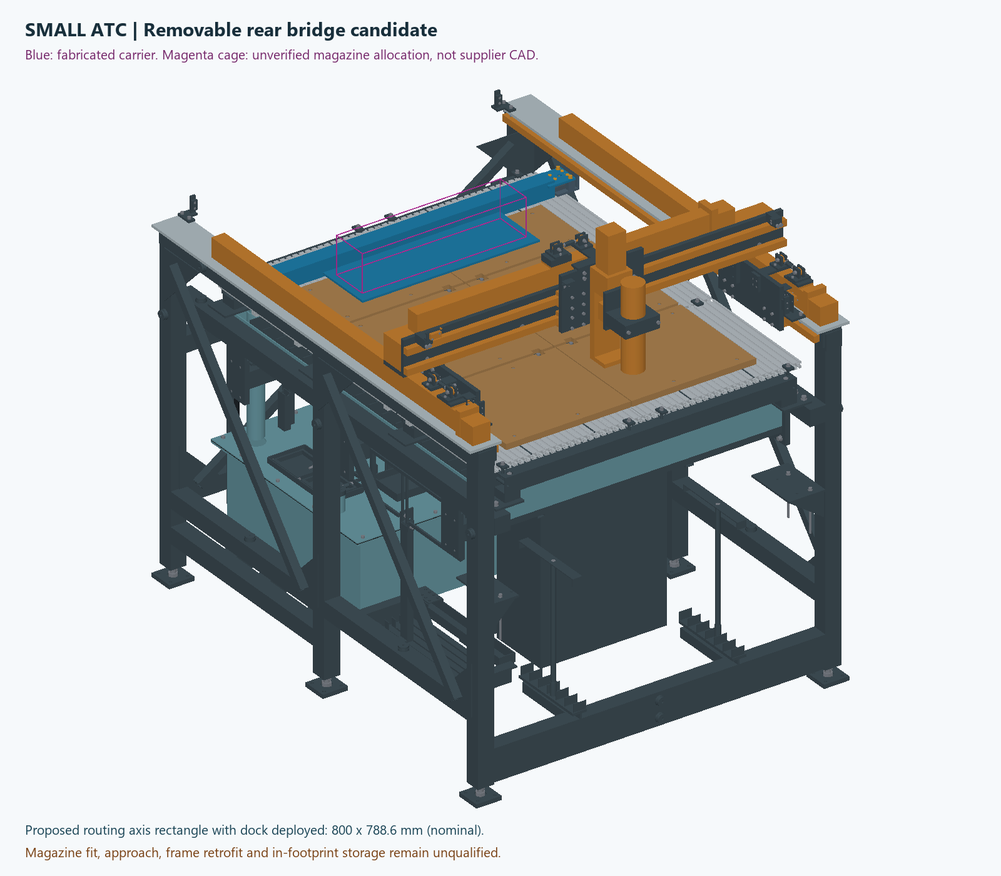
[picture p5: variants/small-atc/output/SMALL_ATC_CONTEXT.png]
Actual candidate CAD


- [Dock STEP](output/step/SMALL_ATC_DOCK_CANDIDATE.step)
- [CAD source](build_small_atc.py)
- [Bounded fit report](output/fit-report.json)
- [Bare-carrier continuous route proof](output/carrier-route-report.json)
- [Preview input/output binding](output/preview-verification.json)
- [Part operations](output/part-operations.json)
- [Manufacturer research and price conflict](../common/atc/README.md)
- [Reserved controls interfaces](../common/controls/ATC-INTEGRATION.md)

## Space and structure

The carrier uses a 906 mm length of 2 × 2 × 0.120 inch square tube, two steel wings and a **560 × 180 × 6.35 mm undrilled shelf**. Its tube ends at X122/1028 leave 2 mm clearance from the fixed pin blocks during extraction. Two proposed welded angle seats connect to the inside faces of the existing upper frame tubes. Four independent hard pads support the carrier, with three primary pads and a fitted fourth. A round/diamond locator pair establishes lateral position. Four M6 drawbolts clamp the carrier; the locator pins are not vertical supports.

The shelf occupies X295–855 / Y950–1130 / Z959.8–966.15 mm. The crossbeam is behind the MDF at Y1130–1180.8. The carrier underside clears the finished MDF by **1.0 mm nominally**, so this layout depends on bed flatness, squareness, clean surfaces and limited deflection. It is a packaging candidate, not a proven operating gap. The new frame welds and carrier stiffness still need load-based qualification; no strength rating is implied by a valid STEP.

The fixed blocks have Ø11 × 6 mm counterbores for flush M6 heads, and the receivers use M5 tapped holes for top-down screws. The ATC-specific left/right receiver parts move their outer M5 columns 5 mm inward to retain full bearing after the outer carrier wings are trimmed for turning clearance. Eight M5 × 16 ISO7380 button heads use the conservative Ø9.5 × 2.75 mm envelope from [HPC Europe's dimensional sheet](https://shop.hpceurope.com/pdf/gbPDFauto/BHC.pdf). Both locator attachments use match-reamed Ø4 dowels; clearance screws alone do not establish repeatability. Installed fits and pin clocking follow the [common locator interface](../common/location/README.md).

The final metal stack uses fixed seat Z964, receiver underside Z978, receiver top/wing underside Z990 and wing top Z996.35. Each 26 mm support pad bears directly against the wing. The CAD calculation checks all four 20 × 14 mm bearing footprints minus the clearance bore. It also records 5.25 mm material beyond each outer M5 head and 6 mm beyond each outer M6 washer. These are geometric bearing checks, not a bolt/weld capacity rating. The `receiver_underside_mm` metadata refers specifically to the receiver, not the low shelf or tube.

With the dock deployed, the proposed full-Z **nominal tool-axis rectangle is 800 × 788.6 mm**, X175–975 and Y121.4–910. It still needs a complete sweep with actual tools. It is not a qualified work envelope or a promise that every stock edge or clamp is machinable. The earlier suggested Y940 rear cutoff is insufficient at low Z: the spindle body's 32.5 mm radius approaches the plate starting at Y950. The Y910 limit retains a nominal 7.5 mm planar clearance. Above Y910, motion belongs to a dedicated retract-and-ATC procedure; it is excluded from ordinary routing.

The inherited spindle lower envelope at full retract is Z1060. Relative to the magazine shelf at Z966.15, that gives **93.85 mm apparent clearance**; the crossbeam is higher, at Z1003.8. Its simplified geometry does not identify the actual nut face, installed cutter tip or RapidChange socket datum. Consequently it does **not** prove the manufacturer's 90 mm clearance requirement or an engagement move. The magenta 520 × 120 × 120 mm cage is an unverified webpage-metadata allocation. It must never be machined or bought as if it were supplier CAD.

## Verification boundary

The fit report checks 63 dock solids and STEP readback, internal interference, six explicit router poses against the complete inherited machine, and the unverified allocation volume at a retracted approach pose. Five intended placements are clear. It deliberately includes the rear low-Z case as a rejection case: the dock occupies part of the original travel. The 120 mm high allocation volume also intersects the retracted spindle; that scenario cannot be accepted as a working magazine envelope. These are bounded static checks, not a continuous routing-envelope proof. A center X575 / Y910 / Zlift0 case is separately recorded in the carrier-route report.

The separate bare-carrier handling proof covers 17 named moving parts through five continuous segments (85 individual solid/segment checks). Exact minimum distances and conservative displacement bounds cover the paths. The two pins during coaxial extraction use an analytic containment check: maximum pin Ø9.995 versus minimum installed bush Ø10.013, with a narrowing tip and Ø12 wing clearance. The continuous turn stays inside a conservative X59.596–1090.373 / Y414.627–1445.404 mm envelope; this follows face-corner trigonometric extrema, not sampled endpoint acceptance. No actual magazine, leads or lifting apparatus is included.

Frozen Rev I source and acceptance reports are not overwritten. The new carrier weldment is exported as one connected solid. Its magazine hole pattern remains blank. The cage is shown in the context mesh, not included as fictitious purchased parts in the dock STEP or BOM.

## Removal, protection and reinstallation

The checked initial state is manual and unloaded: stop and isolate spindle operation, remove cutting tools, place the gantry at Y275 / X575 / Zlift100, disconnect identified magazine electrical connectors and remove four carrier drawbolts plus four washers. Small-hardware transfer and human access are not included. The 17 moving metal parts, including the carrier, have approximately **10.16 kg nominal mass** at steel density 7850 kg/m³; actual magazine, tools, cables and hardware variation add to this.

The bare assembly has a continuous geometric route entirely within the machine footprint:

1. Lift 20 mm to disengage the locating pins.
2. Translate 225 mm forward in Y.
3. Lower 1 mm so the receiver tops remain below the stationary Y datum strips during the turn.
4. Turn 90° counterclockwise about X575 / Y930.
5. Lift 700 mm into an overhead allocation, ending approximately X540–780 / Y415–1445 / Z1672–1722.8 mm.

This establishes an internal geometry option, **not supported parking or a complete ATC conversion**. Positive suspension, a stationary overhead rest, load restraint and protection have not been designed or rated, and no owned hoist is assumed. The actual magazine and its cover/cord envelope must be added to the proof. A lowered rear storage proposal was rejected; it is not the proposed solution. Do not install the frame seats until the overhead support/transfer mechanism and actual magazine fit are qualified. The original machine remains the fallback without this retrofit.

For plasma mode the HDPE magazine, tools, optics and electrical connections need verified removal into a dry protected enclosure, or a separately qualified heat/splash barrier. The manufacturer's dust cover is not claimed as a plasma splash shield. No air purge, waterproof rating, automated drawer, lift or removal interlock is implied by this CAD. The reserved dock-presence input is only an interface plan until an actual device and location are designed.

On reinstallation: clean the metal datums, seat the carrier, clamp against the pads without lifting a datum, inspect tool clearance, then verify/reprobe the pocket references before enabling M6. An ATC return target of ≤0.05 mm is proposed for a measured 20-cycle test. It is not established performance. Homing repeatability, gantry yaw, temperature, spindle tram and pocket calibration require their own alignment allowances.

## What closes the remaining design

1. Select the exact current ER11 linear magazine and obtain its dimensioned CAD, mounting pattern, cover sweep and electrical specification.
2. Measure the spindle nut, actual retract/engagement datums and available tool-length travel; identify and verify the VFD reverse and low-speed behavior.
3. Replace the cage with supplier geometry, drill the carrier only from that verified drawing and verify continuous approach/retreat with real tools.
4. Design the positive lifting/resting fixture and dry protection for the checked overhead allocation; then repeat the route with the actual magazine and all leads. The existing no-outside-footprint requirement has not been relaxed.
5. Qualify the frame retrofit, pads, deflection, installed locator fits and repeatability; implement and bench-test the separately documented I/O and M6 logic.

The approximately $700 magazine allowance excludes shipping, tax, toolsetter, additional nuts/collets, the dock, electronics and fabrication. There is no defensible delivered total for this optional addition yet.

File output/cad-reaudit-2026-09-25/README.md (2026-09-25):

# Full CAD re-audit — 25 September 2026

**Result: the current CAD is not ready for fabrication or a final CAD/CAM handoff.** The audit records **29 findings: 14 high priority and 15 medium priority**. These include confirmed geometry/documentation defects and missing engineering verification; they are not 29 proven structural failures. Related findings sometimes describe different parts of the same unresolved system.

This audit examined the repository at `554530196701756bd5db9a71d199fd89334f35f1`, plus the new audit scripts and evidence. Existing design sources, STEP files, DXFs, firmware and CAD revision were not changed. Navigation/status annotations were added after the checks. The folder still says Rev E; the current bed design calls itself Rev F.

## Findings that must drive the next design revision

| Issue | Evidence and consequence | Finding |
|---|---|---|
| Swap exceeds the required footprint | The module travels 1400 mm forward and is parked outside the machine. The user explicitly required an in-footprint swap. A winch asserted in source comments is not confirmed owned equipment. | BED01, BED11 |
| Five deck fasteners lack full MDF seats | Three screw axes are 2.3 mm outside the support. Two are only 0.7 mm inside its edge. Their holes, pockets and washers do not have the required support. | BED02 |
| Full support surfacing is unreachable | Rear MDF extends 152.1 mm beyond nominal tool-axis travel. The rear outside corner would require a 167.1 mm cutter radius before clearance checks. The instructed 1 mm skim is also absent from the final modeled stack. | BED03, BED08 |
| Z-adapter DXF disagrees with its solid | Two 30 × 11 mm counter-slot recesses are horizontal in the DXF and vertical in the STEP. Following the drawing removes the wrong material. | MT01 |
| Plasma setup is not an operational plasma assembly | The STEP retains the router clamp, parks the spindle, and has no installed torch, floating touch-off or breakaway. The separate torch-clamp solids lack the mounting and pinch holes described in their notes. | MT02, MT03 |
| Bed anchors and location are unfinished | Modeled weldnuts are separated from ledger metal by 1.494 mm without a defined bridging joint. Locator fits, actual receiver bearing, tightening loads and MDF/extrusion preload need defined, verified details. | BED04–BED07 |
| Fabrication features are missing | Cabinet stringers are solid, unperforated tubes despite notes claiming clearance holes. The drip-cap DXF does not define the instructed folds, bend allowances and corner treatment. | FW-02, FW-03 |
| Water servicing and clearances remain unresolved | A simple rearward lid-removal path strikes the rear brace; other paths are not ruled out. The low-water guard has only 0.672 mm nominal floor clearance. Valve, fittings, hose routes and tool-to-guard clearance remain incomplete. | FW-01, FW-04–FW-06 |
| Rigidity and supplier interfaces are not qualified | Valid solids do not establish full frame/tool-loop stiffness, joint capacity, support stability, actual actuator/rail mounting, or Z retention on power loss. | BED09–BED14, MT05–MT07, FW-07–FW-08 |

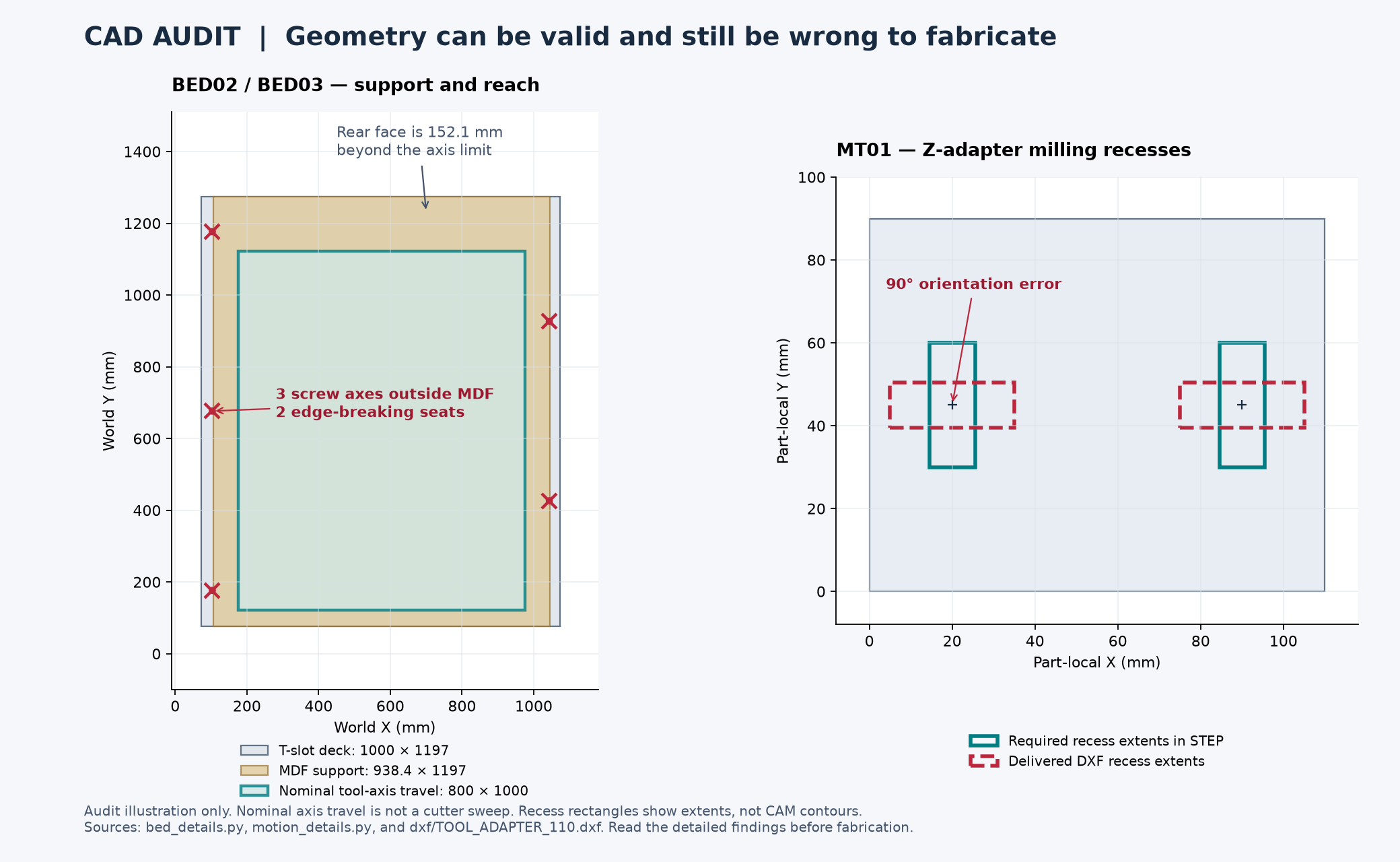
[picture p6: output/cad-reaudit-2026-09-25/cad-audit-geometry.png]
Dimensioned audit examples


The figure is an audit illustration, not a manufacturing drawing. The MDF rectangle shows its overall footprint; local float-guard notches are omitted. Tool-axis travel is not the swept envelope of a real cutter.

## What was freshly checked

| Coverage | Result | Evidence |
|---|---|---|
| All CAD exchange files in the repository | **253 files inventoried and hashed: 168 STEP, 85 DXF.** No native Fusion `.f3d` or `.f3z` is present. | [Inventory](inventory.json) |
| Current source rebuild | **967 valid single-solid components**; every component matches the saved assembled record's bounds and volume within the declared tolerances. No duplicate component IDs or local/world volume mismatches. | [Fresh model](fresh-model.json) |
| Complete current assembly STEP imports | All three import as valid geometry; counts are 967 assembled, 967 router and 731 plasma setup. Hashes match the saved readback reports. | [Assembly STEP checks](assembly-step-checks.json) |
| Every current individual STEP | **162 freshly imported files**; no missing/unreferenced part exports or first-instance source volume/bounds mismatches. | [Individual STEP checks](individual-step-checks.json) |
| Historical Rev D assemblies | All three freshly import as valid geometry. They remain superseded and were not requalified for current design requirements. | [Historical STEP checks](historical-step-checks.json) |
| Every current DXF and nest | **85 freshly parsed files**, all in millimetres with no reported DXF audit errors or open cut polylines. Recorded nesting quantities, boundaries and rectangle overlaps pass. | [Drawing checks](drawing-checks.json) |
| Fresh source-to-DXF comparison | **67 individual drawings** match the current flat generator's entities, machining layers and notes. This proves freshness, not correctness: MT01 reproduces the generator's orientation bug. | [Drawing fidelity](dxf-source-fidelity.json) |
| Shared manufactured part numbers | No unresolved geometry differences after the recorded rotation checks. The two module rails are the same part used end-for-end; the coupler also differs only in orientation. | [Part-number checks](part-number-checks.json) |
| Default assembled static geometry | Zero unresolved positive-volume intersections; **86 explicitly permitted intersections** remain subject to joint review. A permission is not proof of an adequate physical joint. | [Fresh static validation](fresh-static-validation.json) |
| Full-machine router motion samples | **All eight nominal X/Y/Z travel-box corners plus the center**: 967 valid solids each, zero unresolved intersections. | [Nine full-machine poses](full-machine-poses.json) |
| Supplied plasma bed/setup view | Fresh reconstruction of the **731-solid** setup: zero unresolved intersections and no saved geometry mismatches after reproducing the original preview/export sequence. This is not an operational plasma head. | [Plasma setup validation](fresh-plasma-display-validation.json) |
| Corrected motion-only fixture | All five original configurations: **295 valid solids each**, zero unresolved intersections and no local/world volume mismatches. | [Motion audit](motion-tools.json) |
| Bed and frame/water subsystem probes | Fresh bed/ledger reconstruction, joint distances, clamp geometry, guard clearances and selected service-path probes. | [Bed audit](bed-structure.json), [frame/water evidence](frame-water-geometry-evidence.json) |
| Square-tube cut schedule | 28 current 2 × 2 blanks fit five full 20-foot bars with the stated trim and kerf. This is not the entire material purchase list. | [Tube schedule](tube-schedule-check.json) |
| Water analytical checks | 147,456 stored-input logic combinations and three transition scenarios rerun successfully; inventory arithmetic also passes its assumptions. No wet test was performed. | [Water rerun](frame-water-water-verification.json) |
| Source syntax | All 26 inventoried Python sources parse. This is not a full execution or correctness test of every script. | [Source inventory](inventory.json) |

## Corrections to earlier audit conclusions

The earlier **22 motion clashes per state are a checker-fixture error**. The standalone checker starts with rail caps at Z1050; the assembled frame first raises them 6 mm and then applies the holes. Rebuilding the fixture in that order removes all 22 overlaps. They must not be presented as physical machine collisions. The saved `motion-validation.json`, `MOTION-VERIFICATION.md` and package checklist still describe different snapshots; this audit's fresh evidence governs the review. The production checker has not been silently patched.

The right-edge MDF screw margin is **0.7 mm**, correcting the earlier 0.9 mm arithmetic. The support defect remains. The shared `MOD_RAIL` part number is valid under the demonstrated end-for-end rotation; an untranslated coordinate difference alone would have produced a false defect report.

The plasma comparison also exposed a checking subtlety: OpenCascade bounding boxes can include cached preview triangulation. The original exporter meshes the router before copying the plasma state. Reproducing that order resolved 620 initial bounding-box differences; component volumes were unchanged throughout. Those differences were not classified as design defects.

## Requirements and dimensions retained

| Item | Current basis |
|---|---|
| Requested travel | X800 × Y1000 × Z100 mm |
| Nominal tool-axis rectangle | X175–975; Y121.4–1121.4 mm, dependent on the unresolved tool/Z stack |
| Bare T-slot deck | 1000 × 1197 mm; ten 1197 mm strips from five two-packs |
| Current assembly bounds | 1206.8 × 1479.2 × 1370 mm, represented hardware only |
| Workplanes | Bare deck Z940.8, optional spoilboard Z959.8, plasma slats Z850 mm; skim/process inconsistency remains BED08 |
| Bed conversion requirement | Must remain within the machine footprint; current forward-hoist architecture does not comply |
| Owned aluminum | Reported 12 × 12 inch pieces in 1/2 and 3/8 inch thickness; quantity, alloy, usable thickness and flatness are unverified. The full-sheet nest is not proof that all aluminum parts fit those owned pieces. |
| Existing cutter | Owner-reported VIV ARC CUT-50; exact start method, revision, torch assembly and CNC interfaces unverified |

## Repair order

1. Restore an in-footprint bed exchange and define its supported/locked/stored states. Model the entire handling mechanism before optimizing details of the rejected forward-hoist route.
2. Define achievable bed datums, support seats, anchor joints, location fits, final skim thickness and controlled fastening. Verify the full structural load path against stated cutting loads and an explicit deflection target.
3. Correct the adapter recess drawing and complete all fabricated clamp, cage and folded-sheet features. Regenerate parts, drawings, operations and nests together, then compare actual feature geometry.
4. Finish the selected motion interfaces, power-loss Z retention, installed router cutting tools and operational plasma head. Add leads, hose bends, way protection and dual-Y skew limits.
5. Complete water connections and service paths, then rerun the assembled states, full travel and exchange path with manufacturing tolerances and real component dimensions.
6. Update the bill of materials and current status reports from the accepted geometry. Only then prepare the fabricator's machine-specific CAM, workholding and postprocessor setup.

## Reports and scope limits

- [Bed, exchange module and structure — 14 findings](bed-structure.md)
- [Motion and tooling — 7 findings](motion-tools.md)
- [Frame, water and cabinet — 8 findings](frame-water-packaging.md)
- [Combined findings register](findings.json) and [repair checklist](repair-checklist.md)

This is a full inventory and current-package CAD/source audit, not physical certification or a claim to have found every possible defect. Interference checks use nominal solids and sampled positions; no continuous swept-volume proof, tolerance simulation, complete stiffness/strength qualification, lifting-system certification, electrical qualification or physical commissioning was performed. Purchased envelopes remain approximations. Historical concept PDFs, firmware and live supplier prices were not re-audited in this CAD-focused pass. No manufacturing G-code was created and Fusion was not launched.

Reproducible checks are in `run_cad_audit.py`, `check_full_machine_poses.py`, `check_plasma_display_state.py` and `frame-water-geometry-check.py`. The main geometry checks used Python 3.12.14, CadQuery 2.7.0 and ezdxf 1.4.4. Run them in a compatible environment; they write evidence beside the audit scripts and leave the design exports unchanged.

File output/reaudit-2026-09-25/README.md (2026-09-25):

# Full-project re-audit - 25 September 2026

Status: **three source-audit reports recorded; findings remain open and design is not released**. This bounded audit was documented for the private GitHub snapshot. It does not include physical commissioning, a fresh complete firmware build, or independent qualification of every purchased component.

The current mechanical source identifies a Rev F one-piece hoisted module. Older Rev E six-cassette records remain elsewhere. Evidence must be tied to actual file contents and source hashes, not simply to a revision label or an old PASS result.

Independent review workstreams:

- [Mechanical audit](mechanics.md) and [evidence JSON](mechanics.json): 10 findings covering motion, bed support/fastening, reach, handling, fabrication and validation freshness.
- [Controls and water audit](controls-water.md) and [evidence JSON](controls-water.json): 8 findings covering controller baseline, firmware, interlocks, water inventory/transfer and electrical definition.
- [Parts and BOM audit](parts-bom.md) and [evidence JSON](parts-bom.json): 10 findings covering selected parts, compatibility, quantities, raw-stock coverage and mixed-revision BOM entries.

Confirmed concerns include MDF surfacing beyond nominal tool reach, bed screw positions at or outside MDF edges, claims about extrusion-lip loading, mixed Kraken/Rodent control definitions, and a BOM that still includes the earlier bed materials. Current motion-verification data contains reported clashes while older prose says zero; the audit distinguishes a possible checker-fixture problem from a proven physical collision. The detailed reports govern the evidence and limitations of each finding. These concerns have not been silently corrected in the CAD during repository preparation.

**T-slot cutting conflict:** current Rev F source uses ten strips cut to 1197 mm, while older purchasing records still instruct thirty 397 mm cuts. Five two-packs contain ten bars in both cases, so an unchanged pack count does not validate the cutting instruction. Resolve the adopted bed revision before cutting.

The original user requirement was for mode conversion within the machine footprint. The newer hoisted-module source requires a separate scope check against that requirement and any subsequent owner instructions. Do not infer ownership or approval of a hoist from a comment in a source file alone.

## Owner identification follow-up

The owner subsequently identified the cutter as **VIV ARC CUT-50**. See the [identity follow-up](CUTTER-IDENTITY-FOLLOWUP.md). The historical reports above retain their original evidence; CW-02 remains open for the exact version and cutter-facing interfaces.

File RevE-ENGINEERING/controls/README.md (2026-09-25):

# Kraken V1.1 hybrid motion controller — engineering implementation

This folder contains an actual compiled grblHAL STM32H7 board port for the Kraken V1.1, with X/Y1/Y2/Z on its four S1–S4 integrated TMC2160 channels. It has independent dual-Y homing and the upstream plasma plugin's live Z step injection. No external stepper drivers are used. The binary passed the static and compiled-image checks recorded in `verification.json`; it has **not** been booted or electrically tested on a Kraken. This is a prototype commissioning build, not a claim of completed machine acceptance.

## Delivered files

- `firmware/kraken-v11-hybrid.bin` and `.elf`: the single combined firmware image.
- `grblhal-h7/boards/my_machine_map.h`: board pin allocation.
- `grblhal-h7/Src/kraken_board.c`: unused S5–S8 driver enable/CS idle states.
- `grblhal-h7/kraken.ini`: reproducible PlatformIO environments.
- `build.ps1`, `verify_port.py`, `build-hybrid.log`, `verification.json`: build and checks.
- `source-manifest.json`, `patches/`: pinned upstream revisions and local changes.
- `COMMISSIONING.md`: ordered physical acceptance procedure and mode settings.

The selected image supports both router and plasma. Plasma mode `$350=0` disables the plasma motion hooks on controller boot; `$350=2` enables external Arc OK / UP / DOWN THC. A cold controller reset is required after changing this setting. Tool power must be inhibited throughout switching. The hardware mode selector must independently connect the enable request to only the selected tool. Mode changes are not performed inside a running job.

## Exact motor allocation

| Function | Kraken socket | STEP | DIR | EN (active low) | CS | Limit input |
|---|---|---|---|---|---|---|
| X, 800 mm | S1 | PC14 | PC13 | PE6 | PD6 | PC15 |
| Y1, 1,000 mm | S2 | PE5 | PE4 | PE3 | PD5 | PF0 |
| Y2, independent home switch | S3 | PE2 | PE1 | PE0 | PD4 | PF1 |
| Z, 100 mm | S4 | PB9 | PB8 | PB7 | PD3 | PF2 |

S3 is grblHAL motor M3 ganged to Y; it is not a fourth G-code coordinate. SPI is SCK PC6, MISO PC7, MOSI PC8. S5–S8 remain unused, disabled, and deselected. No sensorless homing is used: remove the corresponding DIAG-to-endstop jumpers according to BTT's manual and use physical switches.

**Only Kraken V1.1 is covered.** Its S1–S4 sense resistors are 0.050 ohm; the library parameter is **50 milliohms**. Kraken V1.0 uses 0.022 ohm on these channels and must not use this image. S5–S8 have another sense value and must not be substituted into the map. BTT's official example uses the `tmc5160` register interface for the board's TMC2160 chips; this port uses grblHAL's corresponding SPI implementation. Physical SPI register readback remains an acceptance test.

Default motor current is **500 mA RMS per logical axis**, including both Y drivers. This is a low-energy unloaded commissioning value, not a cutting setting. The Z listing gives 3 A/phase but does not establish how that number maps to a sine RMS driver setting. The X/Y motor current specification remains to be obtained. Do not set 3 A RMS merely because a listing says 3 A/phase. Validate motor/vendor definitions, then thermal-test the chosen current.

## External connector allocation

| Signal | Physical connector | MCU pin | Electrical interface |
|---|---|---|---|
| Arc OK | EXP1 pin 8 | PD12 | isolated 3.3 V-compatible logic |
| THC DOWN | EXP1 pin 7 | PD13 | isolated 3.3 V-compatible logic |
| THC UP | EXP1 pin 6 | PD14 | isolated 3.3 V-compatible logic |
| E-stop chain status | EXP1 pin 2 | PG4 | isolated status from independent hardware stop circuit |
| Feed hold | EXP1 pin 3 | PG3 | isolated/button logic |
| Cycle start | EXP1 pin 1 | PG5 | isolated/button logic |
| Floating head / router tool probe | EXP2 pin 4 | PE11 | selected probe circuit, isolated logic |
| Machine permissive / breakaway / door | EXP2 pin 7 | PG6 | isolated series permissive-chain status; hardware also removes tool permission |
| Torch / VFD run request | EXP1 pin 4 | PG2 | logic to normally-off isolated output circuit and keyed tool selector |
| VFD speed request | BLTouch SERVO signal | PE9 | 5 kHz PWM to isolated PWM-to-0–10 V converter |

EXP headers expose MCU logic. Their separate 5 V supply pin does **not** make the signals 5 V inputs. Do not connect 24 V sensors, VFD terminals, torch triggers, arc voltage, or plasma work return directly to these pins. All interface signal levels, isolation ratings, default states, and connector orientation must match the final interface schematic. Do not use a heater/fan MOSFET output as a logic substitute.

The mapped free aux input ports are intended as Arc OK=0, DOWN=1, UP=2. Confirm these physical-to-logical mappings using `$PINS` on the actual controller before assigning `$367/$368/$369`. The static test also checks that all 12 interrupt inputs have distinct EXTI line numbers; this avoids an STM32 port-selection collision.

This firmware route uses a separate **arc-voltage-sensing THC with isolated Arc OK, UP and DOWN signals**, not a separate motor driver. Kraken still controls every motor and applies the real-time Z correction. The exact cutter-facing voltage/trigger interface must be supplied by a compatible external THC/interface, following the cutter's documented CNC connection. This build does not decode THCAD frequency and does not accept raw arc voltage. No voltage-reading or anti-void capability is implied by UP/DOWN mode; velocity anti-dive is implemented by the plasma plugin.

The controller's E-stop input is a status/reporting path. The physical E-stop and breakaway chain must independently remove tool permission. Firmware, USB, an SBC, or a GPIO is not the sole stop mechanism. PG2 needs an external normally-off interface so reset, loss of power, and an unplugged controller cannot command a tool.

**Water/bed permissive reservation:** PG6 / EXP2 pin 7 is reserved for the isolated combined machine-permissive status (bed locked, appropriate water state, breakaway and door chain), presented as the safety-door input. The same hardwired chain must gate tool permission independently. The separate relay/float-switch controller owns fill, drain and router-ready logic; Kraken firmware does not run or supervise the water-transfer sequence. If separate diagnostics are desired, add them outside this reserved combined stop/permissive input.

## Build and source

The build uses PlatformIO 6.2.0, `ststm32@20.0.0`, STM32CubeH7 1.12.1, and ARM GCC 7.2.1. Runtime packages are inside this folder's `.platformio`; the Python 3.12 venv is `.venv`. Run `./build.ps1` from PowerShell. It builds only `kraken_v11_hybrid`, then verifies the output. It does not flash any hardware.

For a fresh checkout, create a Python 3.12 venv at `.venv`, install `platformio==6.2.0`, clone the source recursively at the revisions in `source-manifest.json`, and apply the included patches / board files. The existing local source already contains them. The linker file reserves 128 KiB for the BTT bootloader and the last 128 KiB for settings. The H723VG-named upstream linker file has the same 1 MiB flash / memory layout needed here; the actual selected MCU is H723ZG. The linked vector is `0x08020000`; the binary is not a bootloader image.

One small plasma-plugin fix is included: a stored retry count of zero is clamped to one before decrementing, the setting accepts 1–255, and the default is one initial attempt with no automatic re-strike. In this implementation `$360=1`, not zero, means one attempt. Existing nonzero NVS settings are not silently rewritten. All source changes and the plugin patch are delivered, with original licenses retained.

Primary references:

- [BTT Kraken documentation](https://global.bttwiki.com/Kraken.html)
- [BTT Kraken repository, manual and schematic](https://github.com/bigtreetech/BIGTREETECH-Kraken)
- [BTT official pin configuration](https://github.com/bigtreetech/BIGTREETECH-Kraken/blob/master/Firmware/generic-bigtreetech-kraken.cfg)
- [grblHAL STM32H7 driver](https://github.com/dresco/STM32H7xx)
- [grblHAL plasma plugin and mode definitions](https://github.com/grblHAL/Plugin_plasma)

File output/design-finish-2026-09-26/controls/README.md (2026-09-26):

# Rev I controls - one baseline and an actual water wiring model

**Current controller: BIGTREETECH Kraken V1.1, existing grblHAL X/Y1/Y2/Z port, onboard drivers.** The Rodent/THCAD selection appended to an older plasma document is not the current design. No replacement motion controller, outside motor drivers, firmware flash or untested THCAD decoder is introduced here. The upstream source and compiled prototype remain in `RevE-ENGINEERING/controls`.

This revision supplies [a normally-off isolated run schematic and restart prevention](RUN-INTERFACE.md), [terminal-by-terminal connections](TERMINALS.md), a [machine-readable netlist](terminal-netlist.json), and a [finite-delay circuit test](verification.json). The simulator traces voltage through real named contacts and diode directions; it is not the earlier Boolean truth table. It covers the water controls, mode-relay allocation and tool-request gating. Mains power, the certified stop subsystem and the unidentified cutter interface are separate boundaries, not silently simulated successes.

## Changes to the circuit

1. Replace both AH3-3 timers with **Finder 80.01.0.240.0000**, function **AI**. A1 is positive and A2 is 0 V; 15 is common, 18 delayed NO, 16 delayed NC. B1 and 16 are unused. T_CLOSE is nominally 12 seconds on the 20-second range, verified at least 10 seconds. T_DRAIN is nominally 75 seconds on the 2-minute range, verified at least 60 seconds. This resolves the missing documented DC contact rating and avoids using an instantaneous pole as a timed pole. Retain a full timer-power interruption of at least 100 ms when a reset is required. [Finder primary data, printed page 3](https://cdn.findernet.com/app/uploads/S80EN.pdf).
2. Add **680 ohm, 3 W, 5%** flameproof resistors from each timed output to control 0 V, before the ready-OR diode or downstream switches. These establish a minimum resistive contact load even when downstream contacts open. At 21.6-26.4 V and resistor tolerance, each dissipates 0.653-1.079 W. Mount above the backplate on covered, heat-resistant supports, away from wiring and plastic. Common float-chain current remains below the 200 mA design ceiling under the stated conservative coil/input allocation.
3. Use the normal **Schneider XB5AD33** three-position/two-NO selector to operate two **Finder 55.34.9.024.0000** four-pole relays with **94.04** sockets. The extra contacts come from actual relays, not fictional extra selector poles. KM_R and KM_P use poles 1/2 for water functions, pole 3 for tool selection, and opposite pole 4 NC for coil interlocking. OFF opens both selector contacts. Normal mutually exclusive selector operation is required; this ordinary interlock is not a safety-rated fault discriminator. [Selector](https://www.se.com/uk/en/product/XB5AD33/selector-switch-plastic-black-%C3%B822-3-positions-stay-put-2-no/), [relay/socket primary data](https://cdn.findernet.com/app/uploads/S55EN.pdf).
4. Retain the six existing **40.52.9.024.0000 / 95.05** water relays. K_READY's status pole now drives the defined 24 V input load below, rather than an unknown MCU pull-up. The two added tool-command relays are **40.52.9.024.5000** gold-contact candidates for low-level dry interfaces, in 95.05 sockets; their suitability still depends on the actual VFD and plasma-interface contact requirements. No dummy load is added to an unknown cutter trigger. [Finder contact material and socket data](https://cdn.findernet.com/app/uploads/S40EN.pdf).

Pump SSRs, branch fuses, wire sizing and flyback protection retain the selected Rev H definitions. The new wiring uses ten 40.52 relays in total (six water, two tool, one request, one run-arm), two 55.34 mode relays, two 80.01 timers and two existing RM1D060D20 pump SSRs. Account for all of them in the panel and eventual price total. There is no new delivered-price claim.

## Exact controller boundary

| Function | Kraken physical connection | Current electrical definition |
|---|---|---|
| Combined machine permission | EXP2 pin 7 / PG6 | Optically isolated active-low status; configure and verify input polarity on the board |
| Hardware stop status | EXP1 pin 2 / PG4 | Separate isolated status; does not replace the hardware stop circuit |
| Float probe | EXP2 pin 4 / PE11 | [Defined isolated NC float](HEAD-INTERFACE.md): healthy LOW / open HIGH; parked float is not a router touchplate |
| Arc OK / DOWN / UP | EXP1 pins 8 / 7 / 6, PD12 / PD13 / PD14 | Outputs of a compatible isolated external THC; no raw arc voltage or THCAD frequency |
| Run request | EXP1 pin 4 / PG2 | AQY212GS normally-off isolated request, release-to-rearm relays, then hardware permission and selected tool relay |
| Speed request | BLTouch SERVO / PE9 | [C41S isolated speed conversion](SPEED-INTERFACE.md), buffered input, commissioning setting $33=200 Hz |

The [official Kraken documentation](https://global.bttwiki.com/Kraken.html) specifies 3.3 V logic and a 200 x 113 mm board. The current firmware covers V1.1 S1-S4 with 50 milliohm sense resistors; V1.0 is a different current-sense configuration. Existing 500 mA RMS settings are unloaded commissioning defaults. The new water netlist does not change motor settings.

**IF_READY input detail:** HEAD_SAFE -> K_READY:11/14 through XW:31/32 -> 1 kohm, 2 W, 5% resistor -> LTV-817 pin 1. Pin 2 goes to field 0 V. Place a 1N4148 anti-parallel across the LED (anode pin 2, cathode pin 1). On the controller side, pin 3 goes to controller ground; pin 4 goes to PG6 and a 4.7 kohm pull-up to controller 3.3 V. Keep the two ground domains separate. Nominal healthy contact closure pulls PG6 low. The field LED current screen is 19.24-26.74 mA over the specified supply/resistor/Vf limits, and the resistor stays below 0.68 W. That field load exceeds the ordinary relay's 300 mW minimum; it does not expose PG6 to 24 V. CTR, saturation, input thresholds, power sequencing and wiring polarity must be checked on the actual interface. [LITEON primary photocoupler data](https://optoelectronics.liteon.com/upload/download/DS-70-96-0016/LTV-8X7%20series%20%20Rev.S.PDF).

This describes a low-voltage status interface, not a plasma arc-voltage isolator, a finished PCB or HF immunity certification. Do not use it for PWM speed conversion. The [run-interface schematic and limits](RUN-INTERFACE.md) now define the output stage and restart-prevention relays. The [head-interface schematic](HEAD-INTERFACE.md) now defines the isolated PE11 float input and three series NO seated-head contacts driving XH:5/6. It includes actual component/terminal selections, load bounds and delay tests against this circuit. The run and head PCB/layout and physical behavior remain unreleased until verified. An optocoupler's component test voltage does not certify an assembled panel.

## Operator controls and bed confirmation

Use the following complete Schneider controls; these quantities are separate physical devices:

| Function | Part and quantity | Actual block terminals | Required closure |
|---|---|---|---|
| MODE | 1 x XB5AD33 | Two NO blocks, each marked 13/14; tagged MODE_R and MODE_P | Router closes only MODE_R; center OFF opens both; plasma closes only MODE_P |
| SETUP/RUN | 1 x XB5AD25 | 21/22 NC and 13/14 NO | NC closes in SETUP; NO closes in RUN |
| AUTO/DRAIN | 1 x XB5AD25 | 21/22 NC and 13/14 NO | NC closes in AUTO; NO closes in DRAIN |
| FILL | 1 x XB5AA35, green flush momentary | 13/14 NO and 21/22 NC | Press closes NO and opens NC; release reverses both |
| BED CONFIRM | 1 x XB5AG03, key 455 | Two NO blocks, each marked 13/14; tagged BED_R and BED_P | Router checked closes BED_R; center UNCONFIRMED opens both; plasma checked closes BED_P |

Schneider's [complete-device catalog](https://productinfo.se.com/nadigest/5c51d645347bdf0001f1f280/Master/17719_MAIN%20%28bookmap%29_0000052086.xml/%24/_17719042_51082) identifies the maintained positions and contact-body assemblies. The [FILL datasheet](https://iportal.se.com/Contents/docs/SQD-XB5AA35_DATASHEET.PDF) supplies 13/14 NO and 21/22 NC; FILL and XB5AD25 use the same ZB5AZ105 contact body. The [MODE datasheet](https://iportal.se.com/Contents/docs/SQD-XB5AD33.PDF) lists 13/14 NO for its two separate blocks. Block identity distinguishes the pair; the drawing does not invent a second block stamped 23/24. Fit position labels only after the complete assembled switch passes the continuity table above.

The terminal renderer now states **physical contact form** separately from **logical closed condition**. In particular, `setup=true` closes the factory NC contact at SETUP_RUN:21/22; `setup=false` closes its factory NO contact at 13/14. A Boolean inversion in the simulator is not a purchased NC contact. The selected XB5AA35 is a flush button, not a guarded assembly; any added guard still needs a compatible part and mounting detail.

B_CLEAR and B_LOCK are **operator-confirmed configuration contacts**, not automatic bed sensors or torque measurement. The selected [XB5AG03 primary datasheet](https://iportal.se.com/Contents/docs/SQD-XB5AG03.PDF) specifies three maintained positions, two NO blocks and key withdrawal in any position. Its labels are ROUTER CHECKED / UNCONFIRMED / PLASMA CHECKED and must list the six panels, four beams, separate spoilboards, locks and tool exchange inspection. Keep it UNCONFIRMED during conversion. BED_P:13/14 connects through XW:23/24; BED_R:13/14 connects through XW:25/26. These XW numbers are panel field terminals, not contact-block stamping. Key removal does not force UNCONFIRMED. Physical control-station mounting remains to be detailed.

## What the circuit test establishes

The test uses nine pickup/dropout combinations, real latch contacts, timers, diode directions and open field contacts. It checks deliberate start, fill self-hold, normal stop, power return with FILL held, bed/level/stop faults, both single SSR-short cases, mode tool selection and hardware permission loss. The resistor and common float-current calculations include tolerances. Tests are generated from the actual connection graph, with an independent expectation for each sequence.

The short-interruption counterexample is deliberate: a 5 ms loss followed by recovery can resume pumping if a relay takes 50 ms to release and FILL remains held. Ordinary suppressed relays cannot guarantee a latched response to arbitrarily short pulses. The passing fill interruption cases use 150 ms and tool permission interruptions use 300 ms; this is a tested model assumption, not a measured relay limit. Mechanically latched stop/mode controls must not be replaced by brief software pulses. Any requirement to latch shorter transients needs a separately validated fault latch, followed by hardware tests. The test reports this limit rather than hiding it under PASS.

No PL/category claim, stop-distance claim, dual-fault tolerance, automatic standstill proof or verified brake timing follows from this model. Whole-machine release still needs the actual control panel, stop/power circuit, Z restraint behavior, physical run/PWM interfaces, firmware commissioning and identified VIV ARC CUT-50 connection. Those are distinct engineering tasks, not completed by the water simulation.

The [selected speed-converter interface](SPEED-INTERFACE.md) replaces the previously unspecified converter and 5 kHz assumption with C41S Rev1.1 and a 200 Hz commissioning setting. It requires a separate buffered input; the slow PhotoMOS run channel cannot carry this PWM.

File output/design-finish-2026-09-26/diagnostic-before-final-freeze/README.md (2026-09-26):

# Rejected intermediate checks

These reports record the first combined Rev I diagnostic run. The CAD sources
changed while it ran; the rightmost plasma-head position at low Z also had
confirmed collisions with the right Y shoe. These records are retained to show
what was found. They do not qualify the final design. See ../ACCEPTANCE.md for
current reports and exact source identities.

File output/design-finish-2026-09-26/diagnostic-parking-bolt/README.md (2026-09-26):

# Interrupted diagnostic: parked head fastener

The first frozen-source run found I_HEAD_CAP_1_103_17 touching
I_PARK_BOLT_2 by 0.71691 mm3 in both router and stored configurations.
The long runs were stopped for a geometric repair. Any RUNNING state in this
snapshot is an interrupted diagnostic, not an active job or acceptance result.
See ../ACCEPTANCE.md for the final source-matching verification.

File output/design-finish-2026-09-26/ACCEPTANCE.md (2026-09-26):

# Rev I verification index

**Recorded checks: PASS.** Explicit nominal geometry, named handling/service paths, conditional structural arithmetic and bounded circuit-model behavior. This is not a complete fabrication, physical rigidity, electrical safety, HF compatibility or operating-machine release.

| Check | Result |
|---|---|
| [Three assembly states; shared parts; nine router and nine head poses](verification.json) | PASS |
| [Independent current STEP readback](step-verification.json) | PASS |
| [Six spoilboard routes](routes/spoil-transfer-check.json) | PASS |
| [Six panel routes](routes/panel-path-check.json) | PASS |
| [Four support-beam routes](routes/beam-path-check.json) | PASS |
| [Structural arithmetic and nominal states; full-machine rigidity remains unqualified](structure/calculations.json) | PASS |
| [Reinforced storage restraint routes](structure/reinforced-restraint-paths.json) | PASS |
| [Temporary keeper-body transfer](structure/temporary-fixture-transfer.json) | PASS |
| [Water servicing, cabinet plates and enlarged hose sweeps](service/verification-build_revi.json) | PASS |
| [Float, normal breakaway and head machining definitions](motion/mechanism-verification.json) | PASS |
| [Head fastener envelopes and exact individual export inventory](motion/head-package-verification.json) | PASS |
| [Split-head transfer through the phased machine](motion/integrated-verification.json) | PASS |
| [Temporary panel/beam preparation and restoration for head transfer](motion/transfer-staging-verification.json) | PASS |
| [Router tool transfer and its bed-sequence prerequisites](motion/router-transfer-verification.json) | PASS |
| [Changed tool obstacles across the full conversion sequence](motion/conversion-prerequisites.json) | PASS |
| [Conversion prerequisite input-report identities](motion/conversion-prerequisites.json) | PASS |
| [Water/tool terminal graph and bounded fault sequences](controls/verification.json) | PASS |
| [Current generated terminal wiring and reviewed control documents](controls/verification.json) | PASS |
| [Normally-off run interface electrical screen](controls/run-interface.json) | PASS |
| [Current authored run-interface drawing](controls/run-interface.json) | PASS |
| [Isolated head/probe schematic and bounded fault response](controls/head-interface-verification.json) | PASS |
| [Final source-bound assembly exports](../release-review/RevI-CAD/engineering-manifest.json) | PASS |
| [Part inventory, individual solids and drawing package](package-verification.json) | PASS |
| [Head detail rendered from current CAD](head-preview-verification.json) | PASS |
| [Concept PDF build inputs](pdf/build-verification.json) | PASS |
| [Four-page visual review of the current PDF](pdf/visual-review.json) | PASS |
| [Exported panel/beam inventory and nominal mass reconciliation](structure/calculations.json) | PASS |
| [Current RevI_ROUTER file](../release-review/RevI-CAD/step/RevI_ROUTER.step) | PASS |
| [Current RevI_BED_STORED file](../release-review/RevI-CAD/step/RevI_BED_STORED.step) | PASS |
| [Current RevI_PLASMA_HARDWARE file](../release-review/RevI-CAD/step/RevI_PLASMA_HARDWARE.step) | PASS |

The initial findings and rejected diagnostic routes are retained as history. Only the source-matching records above support the current package. A PASS here does not mean the machine is ready to fabricate or operate.

[Open engineering and measured inputs](OPEN-ITEMS.md). [Full hashes](acceptance-index.json).

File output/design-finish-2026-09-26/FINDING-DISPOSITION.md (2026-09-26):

# Original audit findings against Rev I

This records the current design response to all 29 findings from the
[25 September audit](../cad-reaudit-2026-09-25/README.md). The historical audit
is unchanged. A corrected nominal feature does not establish a complete
machine, supplier fit or physical qualification. Current evidence is bound in
[ACCEPTANCE.md](ACCEPTANCE.md); remaining tasks are in [OPEN-ITEMS.md](OPEN-ITEMS.md).

| Finding | Current disposition |
|---|---|
| BED01 — outside-footprint exchange | Forward hoist/cart architecture removed. Small panels, beams and separate boards use internal storage and explicitly checked routes. Head transfer is separately defined. Human handling and tolerances still need demonstration. |
| BED02 — unsupported fastener seats | Defective MDF sub-bed removed. New ties provide nominal washer seats; the actual slot-lip clamp capacity remains conditional. |
| BED03 — unreachable full surfacing | Unreachable full sub-bed skim removed. Six reachable spoilboard faces replace it. Actual cutter/workholding/guard clearance and repeat seating remain open. |
| BED04 — extrusion lips under preload | Captive nut strips are modeled. No ordinary M5 torque-table value is released; specified actual-profile coupon testing must establish permissible preload/uplift. |
| BED05 — unattached weldnuts | Gapped weldnuts replaced by defined bearing plates, bosses and compression sleeves. Current joint instructions specify force targets and conditional load checks. Weld and actual wall quality still require qualification. |
| BED06 — undefined locating fits | Round/relieved locators, engagement and storage receiver fits are defined. Actual manufacturing fits and repeat seating must be measured; clearance-bolted front seats do not automatically return to zero. |
| BED07 — accumulated strip tolerance | Slotted ties provide nominal lateral adjustment. Delivered profiles must fit the available allowance. |
| BED08 — missing skim in stack | Corrected: finished spoilboards are 18 mm after a 1 mm skim from 19 mm rough stock. |
| BED09 — incomplete stiffness bound | Actual bed-section/member calculations and proposed 100 N / 0.20 mm target are supplied. Full tool-to-work compliance remains unqualified; missing motion/joint terms are not assigned zero. |
| BED10 — TEK bed restraint | Original MDF-to-steel TEK joint removed. Current panel/beam joints have different defined load paths; actual fastening capacity still needs qualification. |
| BED11 — omitted sling/support system | Assumed owner winch and sling removed. Manual storage retainers and temporary keepers are modeled. Load screens and routes do not prove human grasp, reach or handling capacity. |
| BED12 — sampled clearance | Specified bed/storage/service/head routes use continuous or conservative swept-solid checks. Router and plasma-head travel corners plus center remain discrete samples; real leads, hands, skew and tolerances are excluded. |
| BED13 — inconsistent handling mass | Current inventory-based density estimates include captive hardware. They remain nominal dry estimates; weigh actual assemblies including residue and installed hardware. |
| BED14 — unreleased frame/pan rating | Braces, seats, storage rods, feet and support demands have conditional screens. Actual stock, welds, floor/contact and complete frame/tool-loop qualification remain open. |
| MT01 — rotated adapter DXF recesses | Corrected in the inherited repair and rechecked through common manufacturing definitions. Unknown purchased output holes remain guarded. |
| MT02 — missing clamp features | Defective old clamps replaced by machined halves, actual attachment/pinch features and a replaceable unbored insert. A production bore requires measured torch evidence. |
| MT03 — absent plasma head | Float/breakaway hardware, stops, magnets, guides and detection are now modeled. The installed hardware state intentionally contains no invented torch; actual torch/start/THC integration is still open. |
| MT04 — false cap collisions | Earlier 22 clashes were a fixture datum error, not machine collisions. Current full-machine poses use the raised rail-cap datum. |
| MT05 — guessed Z output attachment | Fictitious output mounting claims removed. Transfer blank preserves known custom tool-side features while awaiting actual output pattern, thread depth and height. |
| MT06 — mounting and power-off Z retention | Catalog module identity/lead and optional brake-motor envelope are documented. Actual rail/carriage/motor/coupling fit and complete power-loss behavior remain unqualified. |
| MT07 — incomplete operating envelope | Router and new head hardware poses checked. Actual cutter, torch/nozzle, tool leads, workholding, way protection and dual-Y skew still need integrated qualification. |
| FW-01 — incomplete water hardware/service | Supported drain/reducer/flange, tail parking, hose spans, pump orientation and removable strainer carrier now have CAD and service checks. Final measured fitting stacks and wet behavior remain open. |
| FW-02 — missing cabinet bores | Corrected stringer bores retained; new enclosure/rail/gland-cover fastening holes are modeled. |
| FW-03 — undefined folded cap | Replaced by defined sloped welded roof/lip/tabs; there is no fictitious folded-sheet development. |
| FW-04 — obstructed reservoir lid | Two accessible gasketed hatches, internal cover parking and washout provide the intended service route. This does not certify removal of the entire loaded lid or reach to every internal surface. |
| FW-05 — floor/guard clearance | Guard elevation corrected, retaining the specified minimum as-built clearance and wet calibration requirement. |
| FW-06 — guard/tool clearance | Head hardware is checked at travel extremes. Actual nozzle/cutter, useful cutting area and guard clearance remain dependent on measured tooling. |
| FW-07 — frame/support stability | Conditional stiffness, brace, joint, foot, tipping and sliding screens supplied. No complete physical frame/support rating is released. |
| FW-08 — cabinet service | Correct nominal cabinet/backplate and removable gland plates modeled. Empty front storage racks for service. Purchased door/lock/standoffs, populated control layout and heat rejection remain unfinished. |

No closure percentage is used: several findings concern different aspects of
the same unresolved measured interface or whole-machine behavior.

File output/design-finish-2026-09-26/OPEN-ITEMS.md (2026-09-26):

# What still prevents a complete machine release

Rev I supplies substantial corrected geometry and circuit definitions. It is
not a final order list or a fabrication/operation release. These are specific
remaining inputs and engineering tasks, rather than a request to approve the
manual bed architecture again.

| Item | Current work | What closes it |
|---|---|---|
| Ordered Y and planned X/Z modules | Catalog travel/lead identified; model and transfer blank preserved | Actual base-slot/nut fit, carriage patterns, heights, stroke datums, motor/coupling/pilot dimensions. Use the existing arrival worksheet before cutting their mating holes. |
| Actual plasma torch and cutter | Defined floating/breakaway mechanism; replaceable insert remains blank | Measure barrel and straight grip; identify CUT-50 version, start circuit and documented isolated interface. Record nozzle datum, lead/tether and operating limits. An AG-60 listing is not this evidence. |
| Rigidity and bed connections | Actual-section beam/joint/storage screens, proposed 100 N / 0.20 mm target | Actual motion compliance and full tool-to-work test, sound tube/welds, slip and repeat-seating checks. Actual extrusion coupon must establish permissible M5 clamp load. No normal torque-table substitution. |
| Electrical panel and stop/power/brake system | Kraken baseline, water/tool netlist, isolated run/probe/head-presence schematics, restart prevention and selected speed converter | Finish populated-panel mounting/thermal layout and actual power/stop/brake schematic using received VFD, motor/brake and cutter interfaces; manufacture and bench-test interface hardware and harnesses; commission pins, timing, current and EMI. Router Z zero is manual. Circuit simulation is not this completion. |
| Plumbing end connections | Supported drain, main pressure/suction routes, strainer carrier and service paths | Measure purchased ports/valve makeup/strainer width, select exact fitting stacks within the recorded zones, then leak/prime/flow/overflow and blocked-filter tests. |
| Purchased enclosure | Correct nominal case and backplate; modeled gland covers and drilled chassis supports | Received door/hinge/latch/bottom-cutout/standoff geometry, opening access, gland sealing and populated heat rejection. Modified enclosure rating is unclaimed. |
| Material and procurement | Current mechanical schedule and fixed net 2-inch tube list | Actual scrap usable lengths/wall/condition, aluminum quantity/alloy and current delivered quotes. Earlier cost workbooks do not price Rev I. |

The owner reported Y is on the way and X/Z planned for Monday 28 September.
Unpublished mating dimensions cannot be verified from a generic seller
picture before those parts or exact manufacturer drawings are available.
Known custom geometry remains reproducible; guarded interfaces must not be
turned into guessed manufacturing holes to make the package look complete.

References: [arrival measurements](../design-completion-2026-09-26/motion/ARRIVAL-MEASUREMENTS.md),
[motion ordering interfaces](../design-completion-2026-09-26/motion/ORDER-AND-INTERFACES.md),
[scrap tube inputs](../design-completion-2026-09-26/SCRAP-TUBE-GUIDE.md),
[joint requirements](structure/JOINTS.md), [controls](controls/README.md),
[service details](service/README.md), [head details](motion/README.md).

No order, supplier message, hardware flash, live motion, torch start or cutting
operation has been performed. The public repository is a design record; a
successful push does not change any release condition above.

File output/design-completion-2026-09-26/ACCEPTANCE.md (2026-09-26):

# Rev H CAD verification index

**Recorded checks: PASS.** Recorded nominal CAD geometry and named continuous paths, with source-matching independent STEP readback. This is not a fabrication, operational-plasma, structural, controls or physical-safety release.

| Check | Current result |
|---|---|
| [Integrated solids, shared parts and nine poses](verification.json) | PASS |
| [Independent final STEP readback](step-verification.json) | PASS |
| [Six spoilboard continuous routes](routes/spoil-transfer-check.json) | PASS |
| [Six panel continuous routes](routes/panel-path-check.json) | PASS |
| [Four beam continuous routes](routes/beam-path-check.json) | PASS |
| [Added restraint and temporary capture paths](bed/restraint-paths.json) | PASS |
| [Two temporary C-body tray-to-beam routes](bed/temporary-fixture-transfer.json) | PASS |
| [Integrated hatch and washout service paths](water/integrated-verification.json) | PASS |
| [Final assembly exports](../release-review/RevH-CAD/engineering-manifest.json) | PASS |
| [Current RevH_ROUTER STEP bytes](../release-review/RevH-CAD/step/RevH_ROUTER.step) | PASS |
| [Current RevH_BED_STORED STEP bytes](../release-review/RevH-CAD/step/RevH_BED_STORED.step) | PASS |

diagnostic-before-final-freeze contains superseded diagnostic reports. A historical STEP_EXPORT_STALE/PENDING status in verification.json is superseded only for export readback by the current passing step-verification.json; its geometry/source findings are not rewritten.

Current results do not close purchased-interface measurements, coupling/brake fit and response, the unfinished floating/breakaway plasma head, flexible cable/hoses, rigidity or physical commissioning. Read each linked report for its exact exclusions.

[Complete hashes and provenance](acceptance-index.json).

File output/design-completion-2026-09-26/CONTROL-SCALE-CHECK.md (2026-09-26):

# Motion scale check — 26 September 2026

The selected X/Y HMS40 listings and manufacturer family information identify ball-screw drives with 10 mm lead. The earlier supplier-request draft incorrectly called them belt modules and has been corrected.

The exact Amazon variation data was rechecked after the owner's lead question:

- [B0C7GQTRRX](https://www.amazon.com/dp/B0C7GQTRRX?th=1): `800mm Stroke`, `10mm Lead`.
- [B0C7GN24S1](https://www.amazon.com/dp/B0C7GN24S1?th=1): `1000mm Stroke`, `10mm Lead`.

Both the selected product title and the ASIN-to-variation map agree. Lead is carriage displacement per screw revolution, not screw diameter. This evidence identifies the selected catalog variants; it does not inspect the owner's order or the delivered hardware. Confirm the supplied Y lead by measuring actual displacement per screw revolution before final configuration, using the supplier's handling procedure.

The current Kraken source already assumes screw drives; no firmware scale change is required from this terminology correction:

| Axis | Motor angle assumed | Microsteps | Screw lead | Calculated pulses/mm | Existing source |
|---|---:|---:|---:|---:|---:|
| X | 1.8 degrees | 16 | 10 mm/rev | 320 | 320 |
| Y1 and Y2 | 1.8 degrees | 16 | 10 mm/rev | 320 | 320 |
| Z | 1.8 degrees | 16 | 5 mm/rev | 640 | 640 |

Calculation: `(360 / step_angle) * microsteps / lead`. These are electrical pulse scales, not accuracy claims. Screw lead, motor angle and direction must match the exact delivered variants. Confirm actual displacement before establishing usable travel limits.

Source inspected: `RevE-ENGINEERING/controls/source-overlay/kraken.ini`. The 500 mA RMS defaults are unchanged commissioning values. The motor phase-current labeling does not automatically define a TMC RMS current setting. The prototype binary has not been flashed or physically tested in this task.

No controller build or pin change was needed for this check. The current port covers Kraken V1.1, not the different V1.0 current-sense hardware. Full electrical stop, brake timing, THC/cutter isolation and hardware commissioning remain separate work.

Product references and pre-order interface details are in the accompanying motion completion report; a listing's stroke option does not determine its mounting geometry.

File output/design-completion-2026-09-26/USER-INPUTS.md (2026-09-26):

# Confirmed inputs — 26 September 2026

- Y modules are ordered and on the way. X and Z are planned for Monday (28 September), about two days from the latest message.
- User is shopping a junkyard for 2 x 2 inch square tube to avoid retail steel prices. No actual scrap lengths, remaining wall thickness, grade or purchase price has yet been supplied.
- Keep 800 mm X / 1000 mm Y / 100 mm Z requested travel, current Amazon module selections, onboard stepper drivers, in-footprint bed storage and owner fabrication.
- Compressor and CV-15HS vacuum generator are owned. Neither is connected to the vented water reservoir.
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

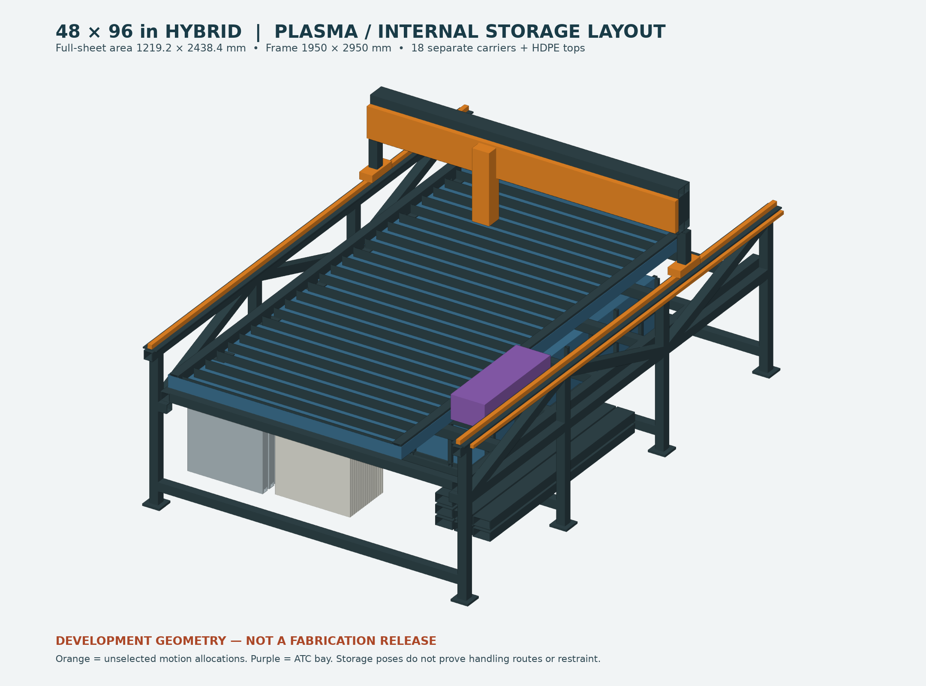
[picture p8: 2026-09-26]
variants/48x96/layout-plasma.png

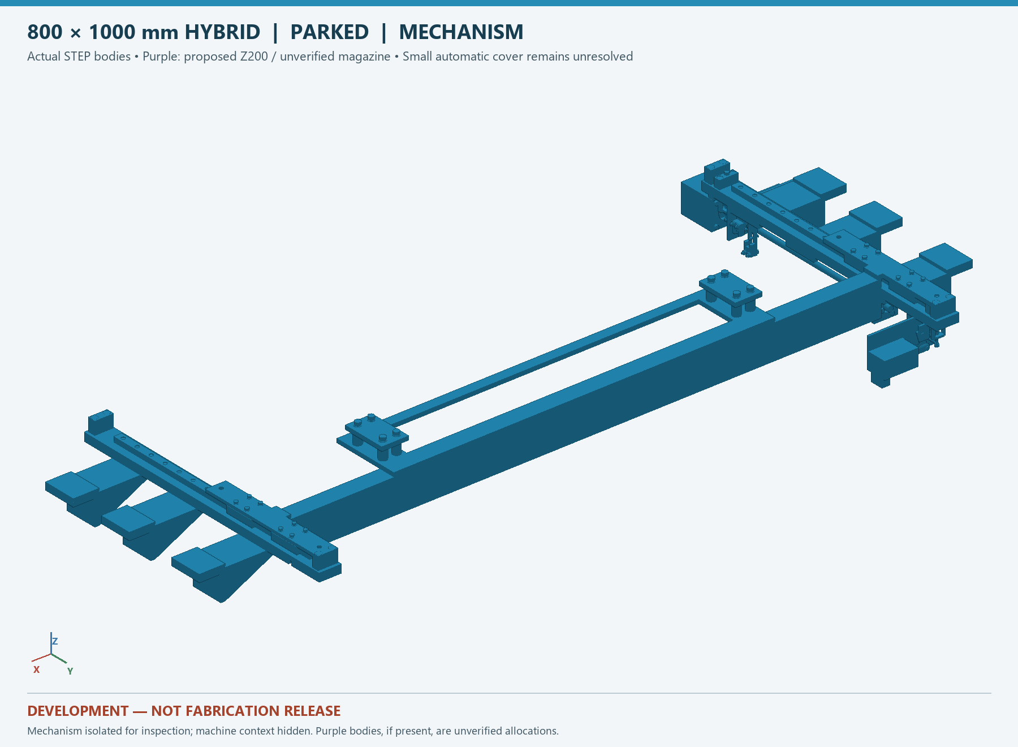
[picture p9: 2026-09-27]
variants/retractable-atc/previews/small-parked-mechanism.png

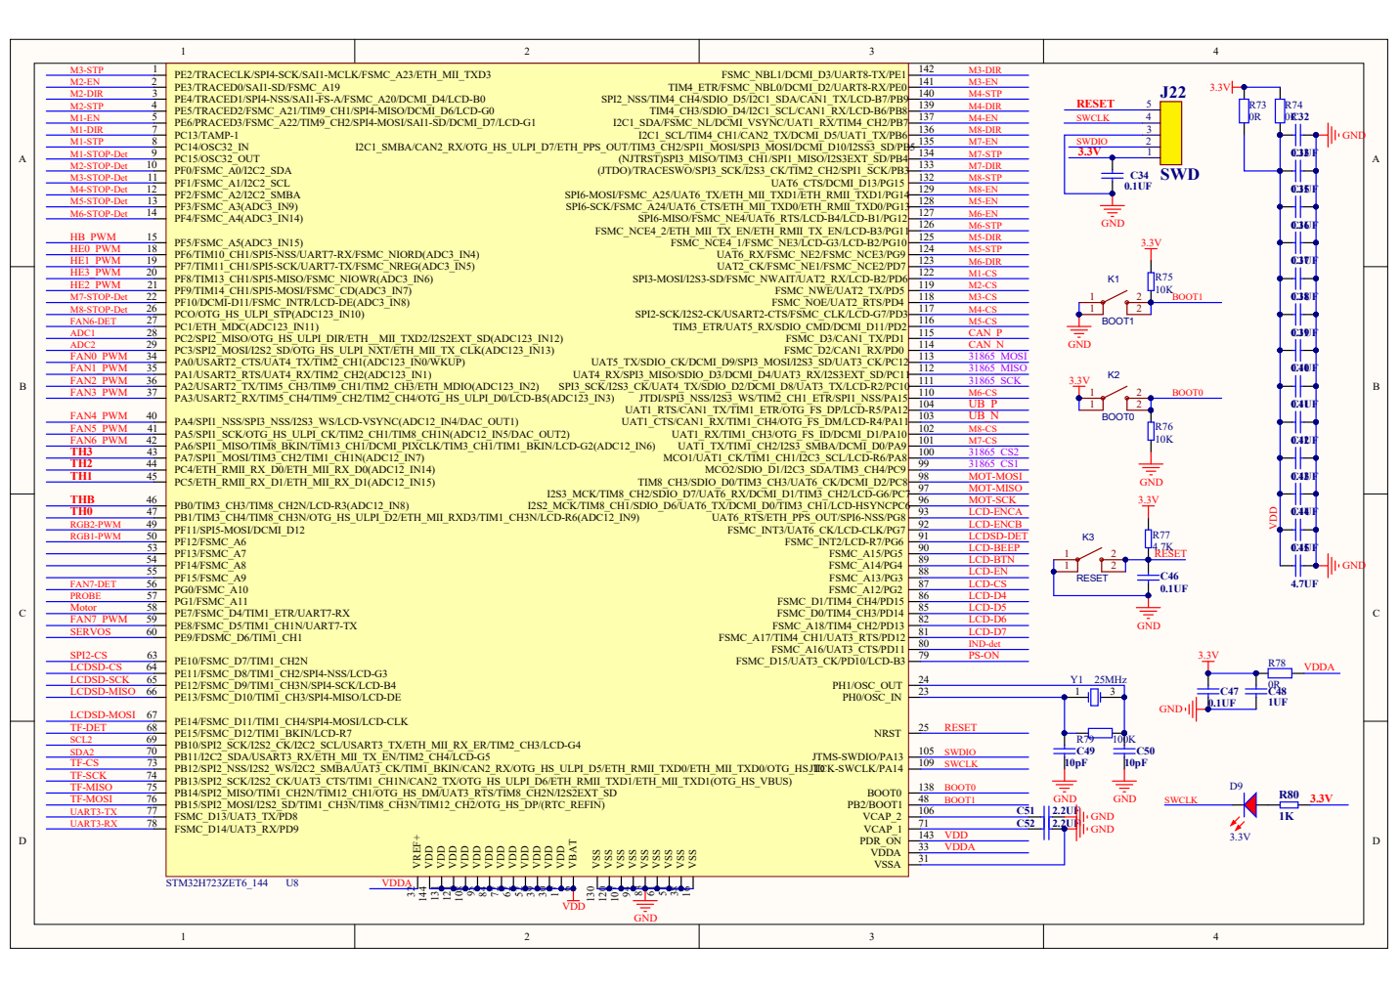
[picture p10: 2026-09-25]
RevE-ENGINEERING/controls/kraken-sch-3.png

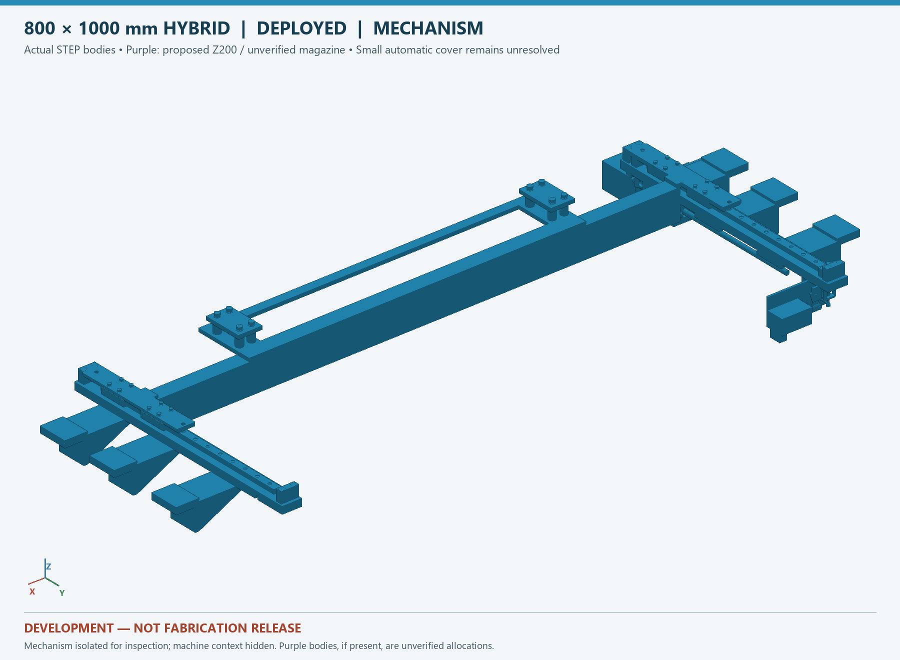
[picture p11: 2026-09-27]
variants/retractable-atc/previews/small-deployed-mechanism.png

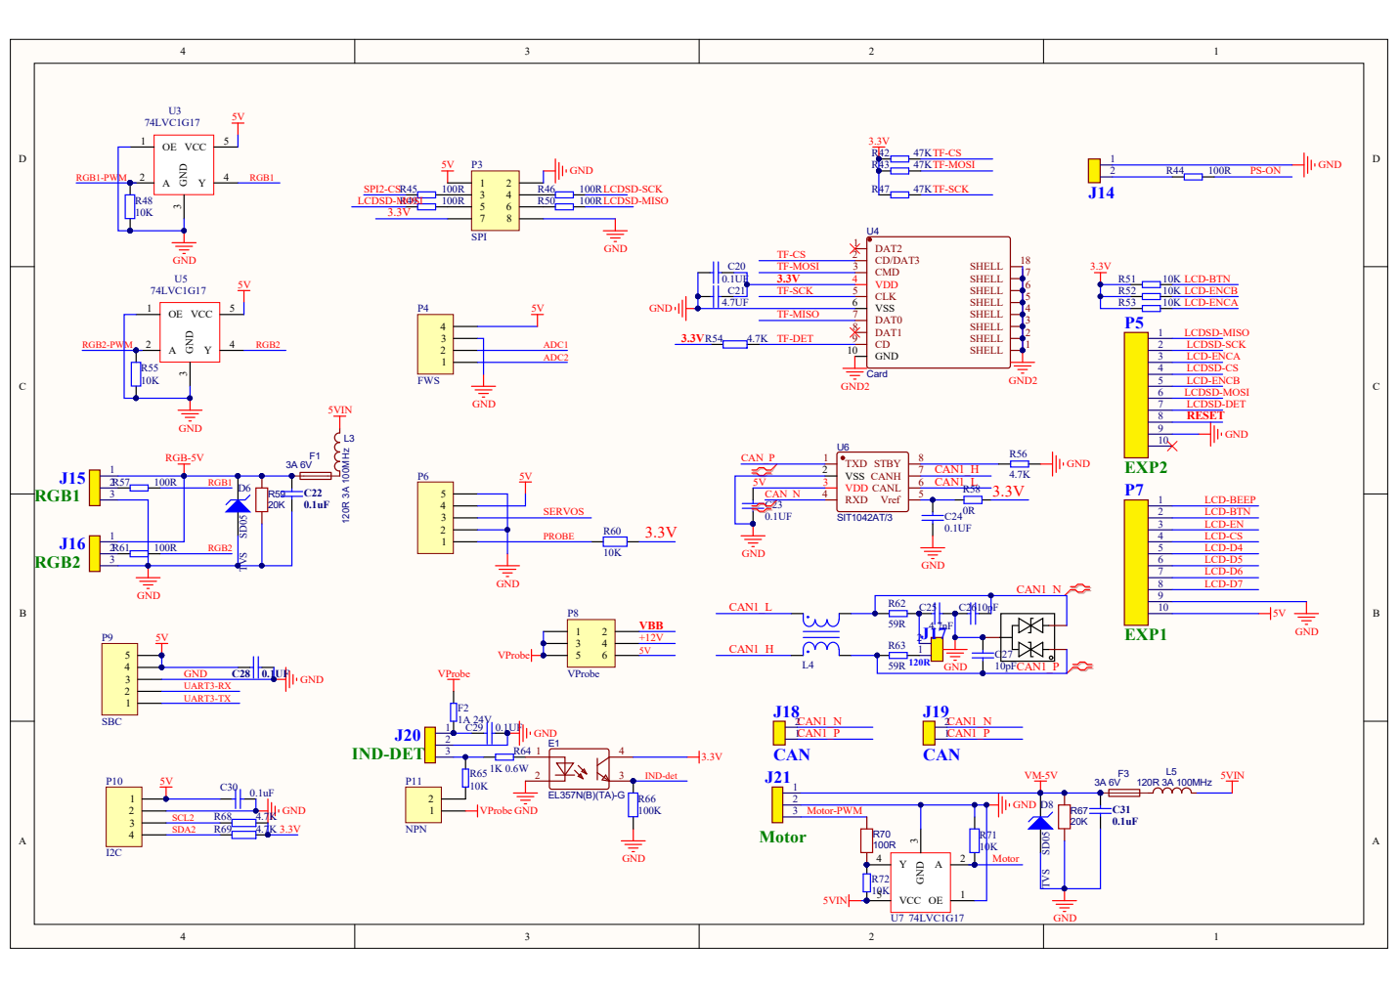
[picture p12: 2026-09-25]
RevE-ENGINEERING/controls/kraken-sch-2.png

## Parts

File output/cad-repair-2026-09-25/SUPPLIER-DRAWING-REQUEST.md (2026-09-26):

# Drawings needed before the remaining mounting parts can be released

These are requests to obtain data, not measurements inferred from photographs.
No supplier message has been sent. The incomplete parts should not be ordered or
cut from the provisional assembly.

## RATTMMOTOR ZBX80, exact 100 mm listing B09MVYGLNQ

Please provide the dimensioned mating drawing for the exact supplied revision,
including:

1. Distance perpendicular from the base mounting face to the output mounting face.
2. Coordinates of all four small output fixing holes from two specified carriage
   edges, including their along-travel spacing. The listing shows a 70 mm
   transverse dimension and a diameter-5 annotation; please confirm the actual
   thread or plain-hole specification, usable depth and backside access.
3. Bottom-slot cross-section, nut drawing and thread, insertion access, available
   engagement and permitted tightening torque.
4. Output position at each end of the 100 mm stroke, limit-switch/stop provisions,
   motor cable projection, moving mass and allowable applied moments.
5. Any manufacturer-supported brake or counterbalance option and its mounting
   envelope. A ballscrew is not being assumed to hold the suspended tool without
   power.

The previous CAD incorrectly associated the 70 mm spacing with larger diameter-7
bores and showed M6 screws. Both claims have been withdrawn. See the
[source evidence](motion/z-interface-resolution.md).

## KHMOS HMS40, exact 800 and 1000 mm modules

Please provide the bottom nut/slot mating drawing, nut retention and assembly
access, usable bolt engagement, reference dimensions from the base ends to the
carriage at each stroke limit, motor current and torque-speed data for the
supplied motor, and the conditions attached to the published load/moment ratings.
The machine's independent guides carry the router loads; these ball-screw modules
provide the drive force through floating links.

## Actual torch and plasma source

The owner identifies the source as VIV ARC CUT-50 and has an AG-60-style straight
torch. The linked torch body is a reference, not a verified complete lead assembly.
Please establish the exact source revision and torch assembly, then provide the
straight insulated barrel diameter/length, permitted clamp zone, nozzle-to-clamp
datum, full head and lead envelope, lead bend radius, connector/pinout, start
method and any documented isolated CNC interface. A generic "pilot arc" label
does not close these fields.

These dimensions are needed before designing the real floating touch-off,
breakaway, torch retention and electrical interface. The stored-bed STEP does not
stand in for an operational plasma-tool assembly.

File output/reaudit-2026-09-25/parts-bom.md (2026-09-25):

# Parts and BOM re-audit — 25 September 2026

**Disposition: NOT ready to order.** This bounded independent audit compares the current Rev F definition with the purchase and cost records. It makes no implementation changes, contacts no supplier, and does not refresh prices. Existing source observations dated 24 September are evidence records, not new verified offers. Mechanical qualification and control firmware are reviewed separately.

## Confirmed current requirements

- The current bed is **1,000 × 1,197 mm**, ten full-length 100 × 20 profiles, rather than the earlier six cassettes. `MECHANICAL-ENGINEERING.md:12` and `cutlist.json:2625` agree.
- **Five two-packs = ten 1,220 mm bars** is the correct pack arithmetic for this layout. Each bar produces one 1,197 mm strip. At 3 mm saw kerf, 20 mm remains per bar before further end preparation. Total finished length is 11,970 mm from 12,200 mm stock. This confirms quantity, not supplier tolerances or flatness.
- The current square-tube schedule contains **28 blanks / 28,356 mm**, fitting **five 20-foot bars**, with 10 mm trim per bar and 3 mm per cut. Three bars have just 6 mm calculated remainder. This is conditional on actual full usable stock length and the stated kerf.
- The cut list carries 50 M5×25 deck screws, 70 DIN 562 M5 square nuts, 20 M5×20 spoilboard screws, 16 #12-14×32 deck TEKs, four M8×70 drawdowns, two Ø10×56 dowels, and four 938.4 mm 2×1.5×.120 crossmembers. Four separate #12-14×38 cabinet TEKs are also modeled.

## Findings

| ID | Severity | Finding and evidence | Required closure |
|---|---|---|---|
| BOM-01 | P1 | **Priced metal quantities still describe Rev E.** `budget-data.json:398` charges MET01 six 20-foot tubes / $930.90 and 36 blanks; current `tube-cut-plan.json:6` calls for five bars / 28 blanks. `budget-data.json:468` also charges $69.28 for deleted cassette tie stock. | Regenerate procurement quantities from the current cut list; preserve old prices as dated evidence. Do not report $5,810.24 as the cost of current Rev F. |
| BOM-02 | P1 | **Deleted bed hardware is still priced while replacement hardware is merely unpriced text.** `budget-data.json:608` onward contains 260 square nuts, 120 M5×12 tie screws, 60 M5×20 screws, 16 M8×80 drawdowns and 60 heavy DIN 7349 washers. Its own lines 1627–1637 declare the old keyhole hardware deleted and require 70 square nuts, 50 M5×25, 20 M5×20 and four M8×70. | Reconcile line by line, retaining any separately justified non-bed demand. Source the new washers/TEKs/drawdowns and remove obsolete reservations; do not subtract a guessed net saving. |
| BOM-03 | P1 | **New rectangular crossmember stock lacks a priced procurement row.** `cutlist.json:2546` requires four 938.4 mm A500 2×1.5×.120 blanks. `METAL-SOURCING.md:15` requests that stock, but the current priced basket contains no matching row. | Add explicit stock specification, cut yield, source and shipping status. Four blanks need 3,753.6 mm net, 3,765.6 mm with four 3 mm cuts, before end trim. One 12-foot bar is too short; one full 20-foot bar fits. |
| BOM-04 | P2 | **T-slot quantity is correct but its cutting instruction is stale.** `budget-data.json:112`, `verified-purchases.json:12`, and `output/bom/extrusion_amazon.json:27` still direct thirty 397 mm strips / six cassettes. Current fabrication calls for ten 1,197 mm strips, one cut each. | Correct all current procurement/cutting exports and mark the old cassette yield historical. Cutting to the stale instruction destroys stock intended for Rev F. |
| BOM-05 | P2 | **The unpriced MDF purchase overstates the half-inch sheet count.** `budget-data.json:1595` calls for two 4×8 half-inch sheets, one 938.4×1,197 layer each. Both layers geometrically fit one 1,219.2×2,438.4 sheet: 1,197+20=1,217 mm across; 2×938.4+3+20=1,899.8 mm along, allowing 10 mm outer margins and 3 mm separation. | Use one half-inch sheet if actual dimensions, defects and finishing stock permit. Thickness after surfacing is a separate unresolved mechanical datum issue; nesting is not thickness approval. |
| BOM-06 | P1 | **Selected motion parts do not yet establish manufacturing fit.** `engineering-manifest.json:198–203` retains unresolved Z output height/along-axis holes/base fastening, HGR20 hole pitch/end conflict, HMS40 base-nut cavity/end datum and motor curves. The 80 mm Z-stack assumption affects tool projection. | Obtain or measure exact interfaces and revise mount drawings, motion limits and cable sweeps. ASIN matching and visual envelopes cannot release these interfaces. |
| BOM-07 | P2 | **Metal sourcing narrative disagrees with the priced ledger.** `METAL-SOURCING.md:5` claims the workbook uses an unquoted $100/bar local allowance and refers to services allowances; the current priced ledger actually uses $155.15/bar, six bars, and owner fabrication labor $0. The table also labels its five-bar figures “Six bars.” | Rewrite against the reconciled current BOM and preserve a clear distinction among posted prices, allowance, owned stock and unquoted freight. |
| BOM-08 | P1 | **Controls ownership and architecture are not synchronized with the cost basket.** `PLASMA-COMPATIBILITY.md:23` onward records owned Kraken/THCAD and a Rodent direction, while `budget-data.json:190–224` still purchases CB1, Kraken and Pi4B. | Controls review must establish the selected architecture and current owned inventory, then retire/retain each purchase explicitly. This audit does not adopt Rodent or certify the appended technical claims. |
| BOM-09 | P1 | **Complete delivered cost remains unestablished, and the existing subtotal is additionally stale against Rev F.** `budget-data.json:7–16` reports $5,734.94 goods + $75.30 known shipping = $5,810.24 partial scope, 43 unresolved scope entries and 17 unquoted shipping groups; complete delivered total is null. | Retain the historical subtotal only as a dated audit snapshot until current quantities, new stock, hardware and shipping are reconciled. Do not treat null shipping as free. |
| BOM-10 | P2 | **T-slot specification has a seller-content conflict, not a closed engineering drawing.** Saved `extrusion_amazon.json:21` records a 100×20 image/title versus a 20×20 bullet. `engineering-manifest.json:94–96` correctly labels its section properties reconstructed, not certified. | Retain exact 1,220 mm / two-piece variant and supplier section image as design assumptions; receive-check actual width/thickness, slot dimensions and DIN 562 nut fit before final hardware release. No fresh supplier verification was performed in this bounded re-audit. |

## User-supplied product mapping

| User reference | Current mapping | Status |
|---|---|---|
| B0C7GQTRRX | M01, KHMOS HMS40, one 800 mm X. Y uses sibling ASIN B0C7GN24S1, two 1,000 mm modules. | Matches nominal orientation; mounting/current/torque-speed interfaces remain open. Saved motion research identifies NEMA23 motors, not unconditional free drivers/sensors. |
| B09MVYGLNQ | M03, RATTMMOTOR ZBX80, 100 mm Z, SFU1605. | Correct selected listing in current BOM; assembled output height and output hole pattern remain provisional. |
| B0FH296V6K | Saved Bestarc BTC500DP reference only. | Not the positively identified owned cutter. Saved listing research reports HF start. Do not add a replacement purchase or declare the owned unit compatible on this basis. |
| B0BF5R3LNC | R01, Zhong Hua Jiang 110 V / 1.5 kW / 65 mm air-cooled spindle kit. | Saved explicit package is **ER11**, not ER17. VFD exact run/speed interface and purchased clamp mounting need confirmation. |
| B07B8CWGB5 | AG-60 straight torch body reference. | Body reference does not establish a complete torch, connector pinout, pilot-start type or cutter compatibility. Current compatibility document records bought ownership; reconcile procurement inventory without claiming a complete working head. |
| B0BXNWK99C | B01, IXGNIJ 20100, silver 1,220 mm two-pack, quantity five packs. | Ten bars are enough for current ten 1,197 mm strips; stale 397 mm cut instructions must be removed from active outputs. |

## Scope boundary

This is a report-only audit. No source model, BOM, PDF, workbook, controls or prices were modified. No order or seller contact occurred. The 24 September supplier observations are reused without representing them as refreshed availability. Whole-machine rigidity, lifting qualification, fastener retention, water-system behavior and electrical/HF compatibility require their separate engineering reviews. The private repository may preserve this as an **unreleased design snapshot**, not a manufacturing package.

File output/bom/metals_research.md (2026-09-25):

# Revision C metal and material takeoff — 24 September 2026

Basis: `output/bed-system/design-parameters.json`, the Rev C material table in `bed_system_pages.py`, and Rev C scene geometry in `build_bed_system.py`. Chassis 1150 × 1450; rail-support height 1050; four paired bridge beams; six 497 × 397 panels. USD; destination Alto, Georgia 30510. No orders or supplier messages sent. Prices below are public observations, **not delivered quotations**. Sales tax, freight, cutting, machining and fabrication remain additional unless stated.

The main purchasing recommendation is to request the exact cut list from **SteelMart Gainesville**, and ask **Metal Supermarkets Buford** or **Cherokee Steel** for metric plate and tube alternatives. Amazon was searched first for 8080 extrusion and the large aluminum plates; this research did not obtain a verifiable Amazon price for an exact 1200 mm standard 8080 or a 497 × 397 × 8 mm plate. Small 12-inch Amazon plates cannot yield the required panel blanks.

## Exact 2-inch tube takeoff

Specify weldable carbon steel square tube **2 × 2 × 0.120 inch**, not 2 × 2 × 0.083. Request ASTM A500 Grade B/C or the fabricator's approved equivalent and material identification. A500/A513 retail descriptions can require confirming the actually supplied specification.

| Assembly | Qty | Cut length mm | Net length mm |
|---|---:|---:|---:|
| Top Y-support tubes | 2 | 1450 | 2900 |
| Fixed receiver ledgers | 2 | 1450 | 2900 |
| Six legs | 6 | 949.2 | 5695.2 |
| Lower side ties | 4 | 648.8 | 2595.2 |
| End ties | 4 | 1048.4 | 4193.6 |
| **Stationary chassis subtotal** | **18** | | **18284** |
| Fixed pan-bearer tube blanks | 3 | 1032.4 nominal | 3097.2 |
| Removable bridge tube blanks | 8 | 1032 | 8256 |
| **Total** | **29** | | **29637.2 mm / 97.235 ft** |

Five full **20-foot / 6096 mm bars** suffice with the following verified nesting. The calculation includes 3 mm kerf per piece and 10 mm total trim allowance per bar. Confirm stock is full usable length and the fabricator's actual saw kerf before cutting; increase allowances if the welder requires rough blanks for final facing.

| 20-foot bar | Cuts, mm | Offcut after stated kerf/trim |
|---|---|---:|
| 1 | 1450 × 4 | 274.0 mm |
| 2 | 1048.4 × 4; 1032.4; 648.8 | 193.2 mm |
| 3 | 1032.4 × 2; 1032 × 2; 949.2 × 2 | 40.8 mm |
| 4 | 1032 × 4; 949.2 × 2 | 41.6 mm |
| 5 | 1032 × 2; 949.2 × 2; 648.8 × 3 | 156.2 mm |

Purchased 30.480 m; finished pieces 29.6372 m; utilization **97.23%**. Offcuts 705.8 mm, kerf 87 mm, trim 50 mm. Do not first cut every stock bar into equal 10-foot halves: that changes the nesting and can increase purchases. Have the supplier cut the actual parts or transport lengths that preserve the nesting. There is no spare full-length tube in this quantity.

A 12-foot alternative needs **9 × 3657.6 mm**, or 32.9184 m purchased, 90.03% utilization. The repeatable calculation and every cut are in `cut_stock_check.py` and `cut_stock_check.json`.

## Remaining takeoff

| Item | Rev C requirement | Purchase / fabrication basis |
|---|---|---|
| Panel frame tube | 25 × 25 × 2 mm carbon steel; 12 × 497 and 18 × 347 mm | Net **12.210 m**, 30 cuts. Obtain cut parts or **2 × 6 m + 1 × 1 m**. Two 20-foot bars are 18 mm short even before kerf. Three full 6 m bars work but leave a large reusable offcut. |
| Chassis diagonal braces | 30 × 30 × 3 mm angle; five braces | Rev C centerline lengths: 2 × 907.331; 2 × 904.060; 1 × 1206.493 mm; total **4.8293 m**. Buy 1 × 6 m, or 1 × 20 ft. These are centerline measurements; final saw lengths and miters follow attachment detail. |
| Rail cap/mounting strips | 2 × 1450 × 100 × 8 mm steel | Net area 0.290 m²; approximately **18.21 kg**. Quote two cut blanks with straightness and final datum machining/shimming specified. Do not expect hot-rolled flats to establish a precision rail plane without finishing. |
| Removable beam end diaphragms | 8 × 101.6 × 50.8 × 6 mm steel | Two per paired beam; end faces plus tube blanks give 1044 mm overall. Quote laser/waterjet or saw-cut blanks; weld distortion/facing allowance remains shop detail. |
| Pan-bearer end plates | 6 plates, 8 mm steel | Two per bearer. Nominal 1032.4 tube + two 8 mm plates =1048.4 span before fit clearance. Plate outline/bolt details remain to be released; 50.8-square footprints are only the tube envelope. |
| Bridge riser feet | 8 feet, finished 30 mm rise | Rendering envelope 40 × 90 × 30 per foot. Final hollow/fabricated vs solid construction, contact pads and screw hardware remain a fabrication quote. Do not buy eight solid blocks solely because the renderer uses boxes. |
| Foot/base plates | 6 × 80 × 80 × 12 mm shown | Approx. 3.62 kg steel before holes; actual leveling-foot hardware/interface controls final plate design. |
| Fixed water pan | 920 × 1200 × 100 mm outside; 3 mm steel; approximately 1% floor slope to sump | Quote fabricated pan with accessible cleanout, welded fittings, overflow and leak test. Floor projection 920 × 1200 plus sidewall allowance totals roughly **1.514 m² / 35.7 kg** of 3 mm steel, before sump/cleats. Flat rendering is not a brake pattern. Floor developed length and trapezoidal sidewalls depend on drainage direction and joint design. |
| Plasma slats | 19 × 880 × 75 × 3 mm steel | Net **1.254 m²**, approximately **29.53 kg**. Quote sheared/laser-cut strips. One 4 × 8 ft sheet yields the slats with ample usable remainder; final slots/comb supports remain additional. |
| Pan plus slat sheet stock | About 2.768 m² net, excluding sump/cleats | Conservatively **2 × 4 × 8 ft sheets** of specified 3 mm steel for separate straightforward nesting. Do not claim one sheet fits just from area. Shop nesting may combine remnants with other 3 mm parts. US 11-gauge/.120 sheet is a thickness substitution requiring measured geometry adjustment. |
| Aluminum subplates | 6 × 497 × 397 × 8 mm | **1.183854 m²**, approx. **25.57 kg**. Six exact finished pieces, or a 1005 × 1205 minimum rough nesting envelope before supplier edge allowance. A 48 × 48 in sheet fits the six pieces in a two-by-three array with 3 mm kerfs. Specify alloy/temper and flatness; Rev C only says aluminum and does not release a plate flatness tolerance. |
| Replaceable MDF | 6 × 497 × 397 × 19 mm | One nominal 4 × 8 ft sheet easily yields six plus spare panels. Actual 3/4-inch MDF is 19.05 mm; measure and surface the assembled deck. Exact datum becomes a commissioning measurement. |
| Gantry extrusion | 1 × 1200 mm standard 8080 aluminum | Use a documented standard section. Profile mass and bending/torsional properties are needed for Y carriage and moment checks. Do not substitute a light extrusion by external size alone. |
| Light skins and front covers | 1.5–2 mm flanged aluminum; two approx.503 × 566 covers and four approx.615 × 498 side skins | Front/side visible projected area about **1.794 m²** before flanges and cutouts. A 4 × 8 ft sheet has sufficient area for these faces and modest returns, but final nesting depends on flange geometry. Cabinet interior liner/shelf, rack structure and wet-zone shields are additional. Use fabricated quote until unfolded blanks/supports exist. **Ignore the exaggerated 4–5 mm cabinetry thicknesses in the schematic render.** |
| Cabinet/panel/beam rack supports | Full-width 1005 × 550 × 680 mm clear storage | Separate load-bearing rack crossmembers, padded supports and attachments need detailing/quote. Aluminum skins carry no stored-bed load. |
| Vented reservoir | 900 × 500 × 350 mm internal, 157.5 L gross; 125 L usable return capacity | Quote material suitable for the liquid/additive, baffles, sludge cleanout, cover, vent, pickup, overflow and support shelf. Wall thickness/material and final external envelope are not released; **not included in pan sheet allowance**. |
| Small interface materials | Motor/gantry/head adapters, gussets, receiver seats, pads, caps, fill/drain bungs, clamps, locating inserts, fasteners | Not all dimensions released. Obtain a separate allowance/quote rather than claiming omitted pieces cost zero. |
| Dry sand | Approx. 58 kg in the stationary chassis only | Three 50 lb bags =68.0 kg purchased if that retail pack is chosen. Actual fill volume depends on ports/closed compartments. Keep sand out of removable beams and deck frames. |

## Public price observations and regional options

All observations accessed 24 September 2026. Search-index prices and live-page prices sometimes differed; the latest directly readable page is used where available. Stock labels are not confirmation of allocation or delivery to 30510.

| Source and item | Observed price USD | Application and delivery status |
|---|---:|---|
| [SteelMart Gainesville](https://steelmartatlanta.com/steelmart-gainesville-ga/) | Quote required | 455 Industrial Blvd, Gainesville GA30501; **770-297-6675**. Will-call/counter sales, cutting and delivery offered. Current stock, all cutting fees and Alto delivery cost require a quote. Regional first choice for chassis stock and cut sheet. |
| [Metal Supermarkets Buford](https://www.metalsupermarkets.com/location/buford/) | Quote required | 4908 Golden Parkway, Suite400, Buford GA30518. Cut-to-size service; listed delivery area includes Cornelia. Delivery to Alto, exact stock and charge remain unconfirmed. |
| [Cherokee Steel](https://cherokeesteel.com/) | Quote required | 196 Leroy Anderson Rd, Monroe GA30655; **770-207-4621**. Carbon steel/aluminum, bandsaw/plate saw/waterjet services. Ask for exact metric and finished plate alternatives; shipping not quoted. |
| [Looper's 2 × 2 11-ga tube](https://www.loopersmetalworks.com/metal-products/) | **$4.03/ft; $80.60 per20ft; $403 forfive** | Published stock-price list dated9/17/26; $3/cut and possible partial-length uplift. **Oklahoma benchmark**, not local quote. Confirm actual wall; no Alto freight quote. |
| [Bobco exact2 × 2 × .120 tube](https://www.bobcometal.com/hot-rolled-steel-square-tube-2-inch-x-0-12.html) | **$97.50 per20ft; $487.50 forfive** | Price visible in indexed supplier listing; direct page returned403. A500B listing, Los Angeles pickup. Georgia shipment/freight unverified; use as benchmark, not recommended distant freight order. |
| [Online Metals exact2 × 2 × .120, part10343](https://www.onlinemetals.com/en/buy/carbon-steel/2-x-0-12-carbon-steel-square-tube-a500-a513-hot-rolled/pid/10343) | **$202.30 per20ft; $1011.50 forfive**; **$100.72 per12ft; $906.48 fornine** | Directly readable latest product page. Cuts and freight to30510 additional/unquoted. A500/A513 designation; confirm supplied grade. Earlier indexed prices were lower and were superseded. |
| [Parker Steel metric catalog](https://www.metricmetal.com/wp-content/uploads/2024/05/RG-201123-FULL-CATALOG-COMPRESSED.pdf) | Quote required | US metric supplier catalog lists **25 × 25 × 2** square tube,1.442kg/m. Confirm current allocation, length options, cuts and freight. Exact-dimensional route for panel frames. |
| [Online Metals / A-Z Metals1 ×1 ×.083 tube](https://www.onlinemetals.com/en/buy/carbon-steel/1-inch-x-083-inch-carbon-steel-square-tube-a500-a513/pid/mp-00064364) | **$15.58 per60-inch piece; $140.22 fornine** | Page says2-business-day ship lead from Mesa AZ; arrival/cost to30510 unconfirmed. **Not exact25 ×25 ×2:** section25.4,wall2.1082. Nine5ft pieces nest the RevC lengths, but using them requires innercuts346.2 instead of347 and revising panel stack+.4mm; price comparison only. |
| [Steel Supply LP1¼ ×1¼ ×⅛ angle](https://www.steelsupplylp.com/sku/100002) | **$24.19 per20ft** | Near-size31.75 ×31.75 ×3.175 benchmark for30 ×30 ×3, not automatic substitute. Page marks freight shipment; stock messaging is ambiguous. No delivery amount. |
| [Looper's11-ga4 ×8 sheet](https://www.loopersmetalworks.com/metal-products/) | **$173.60 each; $347.20 fortwo** | Oklahoma published raw-sheet benchmark; shear fee listed separately. Actual3mm vs11gauge must be resolved. Fabricated pan, slope, drain fittings, leak test and slat cutting additional. |
| [Online Metals3 ×⅛ flat, part10007](https://www.onlinemetals.com/en/buy/carbon-steel/0-125-x-3-carbon-steel-rectangle-bar-commercial-quality-hot-rolled/pid/10007) | **$18.14 per72-inch; $181.40 forten** | Ten6ft bars yield20 ×880 slats with3mm kerfs and one spare. This is76.2mm high ×3.175 thick stock, requiring trimming/clearance updates for RevC75 ×3. Freight unquoted. Alternative to sheet-cut slats, not additive to the two-sheet pan/slat allowance. |
| [Online Metals exact8mm5754, part29508](https://www.onlinemetals.com/en/buy/aluminum/8mm-aluminum-plate-grade-5754/pid/29508) | **$902.42 per24 ×36-inch blank; $2707.26 forthree** | Three blanks yield two panels each. Exact thickness but grade/flatness needs acceptance. Public high-cost comparison; request cut-to-size local material before paying this. Freight unquoted. |
| [Online Metals5/16-inch6061-T651, part14480](https://www.onlinemetals.com/en/buy/aluminum/0-3125-aluminum-plate-6061-t651/pid/14480) | **$759.54 per48 ×48-inch sheet** | Latest directly readable price; earlier indexed$915.25 superseded. One sheet yields six panels; saw cutting/finished edges extra. **7.9375mm**, so it is0.0625mm thinner than RevC8mm and not a silent exact replacement. Lower overall height can be captured in datum setup or shim design after approval of material/tolerances. Freight unquoted. |
| [80/20 standard40-8080](https://8020.net/40-8080.html) | **$0.1231/mm +$4.01 cut = $151.73 for1200mm** | Manufacturer lists6063-T6, Ix=Iy171.6341cm⁴,0.3563lb/in → about7.64kg at1200mm. Cut-only calculation; tapping/other machining, tax and shipping extra. No delivery date/quote to30510. |
| [BCI .080-inch5052-H32 aluminum48 ×96](https://bciimage.com/product/aluminium-sheet-080-5052-h32-0-08-x-48-x-96/) | **$510 per4 ×8 sheet** |2.032mm near-size skin stock. Supplier explicitly requires an extra quote for oversized shipment; **do not call this free delivery**. Stock/ETA confirmation offered. Flange fabrication and finish additional. |
| [Looper's .080-inch5052-H32 aluminum4 ×10](https://www.loopersmetalworks.com/metal-products/) | **$254.64 per4 ×10 sheet** | Lower regional raw-stock benchmark; verify listing/alloy and availability. Oklahoma source, not delivered Georgia price. Quote local equivalent rather than assuming long-distance shipping is economical. |
| [Home Depot3/4-inchMDF panel](https://www.homedepot.com/p/309177124) | **No price observable** | Product page confirms actual19.05mm thickness and49 ×97-inch panel. Local store stock, pickup price and delivery to30510 not verified; leave quote-required. |

## Budget treatment and release conditions

Do **not** add every price row: several are alternative purchase routes for the same part. The five-bar chassis price benchmarks span **$403–$1011.50 for raw stock only**, before grade confirmation, cuts and freight. The gantry extrusion has a concrete manufacturer calculation of **$151.73**. An exact full-machine metal subtotal is not available because metric aluminum, tank construction, cabinet supports, machined seats and interface plates still need quotes/details.

For a reviewable procurement sheet, separate (a) public price-backed line items, (b) explicit dimensional substitutions requiring revision, and (c) fabrication/finish/freight allowances. A local quote must state material and grade, finished/rough dimensions, kerf, tolerances, weld/facing allowances, leak testing, finish, tax, delivery and unloading terms. No amount in this report proves delivery is included.

Useful RFQ wording: “Please price the Rev C29-piece2 ×2 ×.120 tube schedule from five20ft bars, with each piece labeled. Separately price the30-piece25 ×25 ×2 panel frame schedule; two1450 ×100 ×8 rail strips; six80 ×80 ×12 foot plates; eight101.6 ×50.8 ×6 diaphragms; fabricated920 ×1200 ×100 sloped3mm pan; nineteen880 ×75 ×3 slats; and six497 ×397 ×8 aluminum plates. Quote raw material, processing, finish, and delivery to AltoGA30510 separately. Identify any proposed imperial substitution and actual supplied thickness. Please include usable stock length and your cutting tolerances.”

This is a takeoff for engineering review, not released fabrication drawings. Published supplier descriptions and dimensional arithmetic have been checked; a final tolerance stack, flatness acceptance and load test remain machine commissioning work.

## US-stock procurement adjustments to Rev C

For the proposed US purchasing route, quote **1 × 1 × .083 inch panel tube**, **5/16-inch aluminum subplates**, and **3/4-inch MDF**. These are explicit procurement adjustments; the existing concept drawings have not been changed or released.

- Panel frame cuts: **12 × 497 mm** and **18 × 346.2 mm** (the latter replaces347 mm to retain397 mm outside width around25.4 mm tube). Net tube12.1956 m. Prefer **two24-foot bars if stocked**, or two20-foot bars plus a short drop. Two20-foot bars remain too short before allowing kerf.
- Nominal panel stack:25.4 +7.9375 +19.05 = **52.3875 mm**. At920.8 mm panel datum, router surface becomes **973.1875 mm before skim**, compared with972.8 mm in the metric concept. Actual material thickness and final surfacing determine the installed plane.
- Quote two rail strips1450 ×100 ×**7.9375 mm** from5/16 steel instead of8 mm; nominal cap datum changes **−0.0625 mm**. Account for this in rail leveling and head clearance. A4-inch-wide bar is101.6 mm, so it requires width trimming or a documented width adaptation too.
- Keep exact8 mm5754's$2707.26 comparison out of the proposed purchase total. Quote affordable finished5/16 6061-T651 blanks locally, with flatness/finish requirements; the publicly observable Online Metals48 ×48 benchmark is$759.54 before cuts/freight.
- Locating hardware, sleeve lengths, clamp travel and tool-tip clearance still require the measured dimensions. No existing released drawing is implied by this addendum.

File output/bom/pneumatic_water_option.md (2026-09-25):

# Compressor-driven water handling — bounded concept review

24 September 2026. User owns a compressor described as12 CFM and assorted solenoids/venturi valves. Their actual models, pressure ratings, duty cycle, coil voltage, flow coefficients and normal/failure states are unknown. Reuse cost can be entered as **$0, conditional on fit**, with any adapters or replacements separate.

**A compressor can raise and lower a plasma-table water level.** Torchmate's manufacturer guide documents compressed air admitted to a lower chamber to raise water, then venting that chamber to let water drain back by gravity. This confirms the architecture, but does not qualify the present custom tank or supply a safe pressure setting for this machine. [Torchmate5100 user guide, water-table operation p15](https://torchmate.com/uploads/manuals/5100-Users-Guide.pdf).

## Option1: engineered air-displacement chamber

Replace the present vented reservoir with a **purpose-built chamber designed for its declared pressure and vacuum conditions**, approved wetted materials, sludge access, reinforcement, fittings and test documentation. Retain at least125 L usable return capacity after accounting for internal structure, dead volume and operating level. A shallow rectangular package offers a better chance of staying in the rear bay than a conventional cylindrical150 L vessel. This is a fabrication-engineering quote, not an ordinary sheet-metal tank with its vent capped.

Concept air path: compressor isolation/filter → documented regulation and flow limitation → fail-closed supply valve → chamber; a separately controlled vent permits gravity return. Independent pressure protection, high-high liquid stop, pressure indication, safe vent discharge, overflow arrangement and service isolation belong in the engineered package. No automatic restart after lost air/power. Existing solenoids may be reusable only after checking voltage, flow, pressure and whether they work at the near-zero pressure differential of a low-head chamber. The venturi is not needed for gravity return and does not make an unrated tank pressure- or vacuum-rated.

The approximately0.65 m static lift corresponds to **6.38 kPa /0.925 psi** for water, ignoring pipe losses and changing levels. This is a physics check, **not an operating or relief setpoint**. Even1 psi across a900 ×500 mm flat panel produces about **3103 N /698 lbf**. Chamber flat panels, closures, welds and attachments therefore need an actual design, not a guess based on “low pressure.”

Fit constraint: the present reservoir drawing occupies roughly930 ×530 ×380 mm externally. An ideal150 L cylinder at350 mm diameter needs about1559 mm of straight cylindrical length; at500 mm diameter it needs764 mm before heads, fittings and feet, and exceeds the current380 mm reservoir height. A catalog150 L pressure vessel cannot be assumed to fit. Reducing chamber volume to make it fit cannot reduce required drain-back capacity. An independent overflow/vent arrangement must also fit; the existing overflow into a vented reservoir cannot be copied blindly into a sealed chamber design.

Cost scope: chamber engineering/fabrication/testing and regulation/protection package **quote required**. No credible supplier price for this custom fit was obtained. Existing compressor and compatible owned valves are$0 reuse; all modifications, plumbing and protective components remain additional. Keep this option outside the priced base build until a supplier supplies an approved assembly drawing and quote.

If plasma cutting aluminum is within scope, use the water-table manufacturer's material-specific guidance before selecting a sealed lower chamber: Torchmate identifies hydrogen accumulation as a particular dual-chamber issue. [Manufacturer notice](https://torchmate.com/uploads/images/PDFs/SafetyNotice.pdf).

## Option2: air-operated diaphragm refill pump, vented reservoir retained

This is the more directly purchasable compressor-fed path. Keep the fixed pan, gravity drain, open vented settling reservoir and independent overflow. Replace the electric refill pump with an **air-operated double-diaphragm pump**. An air solenoid starts/stops it; there is no air connection to the reservoir headspace. Stop refill on pan high-high, reservoir low-low or changeover fault. Pickup stays above settled sludge; the pump's passage size is not a guarantee of indefinite abrasive-slurry life. Fluid-side hose/fittings must suit the selected pump's possible discharge pressure, with any pressure limiting required by the pump manufacturer; an air-gapped return still prevents siphoning.

A concrete candidate is **Graco Husky307 D32966**, polypropylene body with Santoprene wetted elastomers, subject to additive compatibility and solids screening. Manufacturer data gives6.5 GPM maximum flow,5.5 SCFM maximum air use and1/16-inch/1.588 mm maximum solids; its operating curve, inlet restrictions and actual compressor delivery determine real cycle time. The larger Husky515 can demand28 SCFM, so choosing it solely for more flow would be a poor match to the stated12 CFM compressor. Pump during changeover when plasma is idle; confirm what pressure the compressor's12 CFM rating refers to. [Graco D32966 specifications](https://www.graco.com/co/es/in-plant-manufacturing/product/d32966-husky-307.html), [Graco pump family data](https://www.graco.com/content/dam/graco/ipd/literature/flyers/345059/345059EN-B.pdf).

The D32966 body is approximately206 ×135 ×206 mm; allow more for hoses, exhaust and maintenance. The current tank-side gaps and space above its lid are too tight to assert a fit without moving components. A rear upper service mounting plate, behind the pan and below the rail datum, is a candidate within the chassis outline. Verify fittings and gantry/head travel before assigning coordinates. Do not enlarge the footprint or shrink the return tank by assumption. [Supplier dimensions](https://www.grainger.com/product/GRACO-Diaphragm-Pump-Polypropylene-911UF4).

Observed **$668.00** for D32966 at FastoolNow on the latest directly readable page, advertised ship lead5–7 business days. An earlier cached view showed$764.12 and was superseded. General free-shipping promotion has size/packaging exclusions; delivery amount and arrival to Alto30510 remain unverified. [Price source](https://fastoolnow.com/graco-d32966-husky-307-polypropylene-aodd-plastic-pump-w-npt-standard-air-valve/). Grainger's public alternative was$1237.60; do not add both.

Procurement scope for this option: pump$668 observed, owned suitable air-control solenoid$0 conditional, regulator/filter/isolation/muffler, pressure-suitable fluid hose, adapters, mounting plate and wiring **quote required**. Subtract the replaced electric pump cost when comparing totals. This is an alternate compressor-powered package, not additive to the electric-pump base package. The custom pressure-chamber option is a separate, unpriced alternative to both.

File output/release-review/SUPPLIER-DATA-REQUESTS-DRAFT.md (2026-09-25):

# Supplier data requests — drafts only, not sent

These requests close specific engineering gaps before purchase. A reply must identify the exact variant and drawing revision supplied.

## KHMOS: HMS40, 10 mm lead, 800 mm and 1000 mm travel

Reference Amazon ASIN B0C7GQTRRX (800 mm) and B0C7GN24S1 (1000 mm). We have the HMS40 drawing dated 2026-02-10 showing four M4 × 10-deep carriage threads at 30 × 30 mm, carriage top 65.5 mm, bottom-slot pitch 28 mm and nominal motorized overall length equal to stroke + 201 mm. Please confirm this drawing applies to both supplied Amazon variants, and provide the missing bottom-slot cavity/nut dimensions, usable screw engagement, carriage coordinates at both travel ends, physical stop positions, motor cable projection and supported home-switch attachment. Please supply the motor model, winding current convention, wiring and torque-speed curve at the intended drive voltage, plus the full-stroke screw speed limit. A STEP model would help verify these interfaces.

The proposed application uses separate guides to carry the gantry and cutter moments; the HMS40 units provide axial drive through floating links. The machine is for wood/plastic routing and plasma cutting. Please confirm allowable axial drive force and duty over the complete stroke, and whether your webpage's MY 13 / MP 12 / MR 15 N·m values apply to these exact variants. Identify the moment axes and whether those figures are static limits or operating limits. We are not treating payload mass alone as approval for an overhanging spindle.

## RATTMMOTOR: ZBX80 100 mm, ASIN B09MVYGLNQ

We have the drawing showing an 80 mm-wide, 219 mm-long base and 330 mm overall motorized length, plus the 50 × 90 × 35 mm output-body dimensions and transverse 70 mm hole spacing. Please supply the missing along-travel output-hole pitch, thread size and usable depth; base mounting-slot section and nut standard; base mounting plane to output mounting-plane height; and output position at both 100 mm stroke ends. Confirm the motor-current convention and whether there is any installed power-off holding device. Please resolve the inconsistent M5/M6 descriptions. A dimensioned drawing or STEP for the exact ASIN is needed, not a different travel length or ZBX80 Plus version.

## IXGNIJ: 20100 silver, 1220 mm two-pack, ASIN B0BXNWK99C

We have your 20100 section image with 6.2 mm slot openings, 7.8 mm cavity depth and 1.3 mm lips. Please confirm that section and two 1220 mm sticks per pack apply to the exact ASIN. Confirm alloy/temper, tolerance and straightness/twist/flatness; the advertised ±0.2 mm wording does not identify each controlled dimension. Please confirm use of DIN 562 M5 thin square nuts, nominal 8 × 8 × 2.7 mm, and permissible slot pull-out load. The profiles will be cut into 397 mm supported work-bed strips; they are not assumed to be precision tooling plate.

## iMetrx: HGR20 / HGH20CA guide kits

Reference ASIN B0FFMMPC3B (two 1500 mm rails/four blocks) and B0FFMN9KNC (two 1200 mm rails/four blocks). Your section drawing gives rail hole pitch P = 40 mm and end offset E = 20 mm, which does not produce a symmetrical hole pattern on a 1500 mm rail. Please supply the actual dimensioned hole layout for both lengths, confirm the 4 × M5 × 6 mm block threads, and identify rail material, block preload and straightness class. We intend to trim the two Y rails to 1420 mm and need the exact factory-hole pattern before specifying the cut ends and mounting datums.

## Spindle kit: ASIN B0BF5R3LNC

Please confirm the exact 110 V, 1.5 kW, 65 mm kit contents and collet system, spindle dimensional drawing, mass and clamp drawing with hole pattern/thread depths. Include the supplied VFD model/manual, electrical requirements, control-input specification and recommended cable/shielding. The linked kit is described as ER11; an earlier conversational reference to ER17 is not a separate verified product.

## Local metal supplier / fabrication shop

After the geometry is released, quote the revision-matched cut list separately for material, cutting, bending, machining, welding if requested, delivery and unloading to Alto GA 30510. Specify actual tube wall thickness and sheet gauge/thickness, available stock lengths, kerf/end trim, tolerances and substitutions. Rail-pad machining and receiver-seat finishing must be explicit line items; do not assume as-welded tube faces satisfy the alignment requirement.

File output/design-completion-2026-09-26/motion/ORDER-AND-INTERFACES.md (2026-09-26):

# Motion purchase decision and physical interfaces - 26 September 2026

The two Y modules are already ordered. Keep that selection. The selected X and Z
listings match the requested nominal travels, but the Z assembly is not a
verified ready-to-install tool axis. This distinction matters before Monday's
order: the frame can be designed now; purchased mating holes and power-off
retention cannot be declared solved from the existing pictures.

| Item | Confirmed primary evidence | Decision |
| --- | --- | --- |
| Y pair, KHMOS B0C7GN24S1 | Exact Amazon variation is 1000 mm stroke, 10 mm lead. | Ordered; retain. Measure the supplied mounting nuts, nut access and stroke-end datums on arrival. |
| X, KHMOS B0C7GQTRRX | Exact Amazon variation is 800 mm stroke, 10 mm lead. Same HMS40 family as Y. | Correct intended travel/lead candidate. Base mounting and actual supplied motor current remain to be checked before final plates/current settings. |
| Z, RATTMMOTOR B09MVYGLNQ | 100 mm stroke; 219 mm base / 330 mm overall; 80 mm base width; SFU1605. Current listing specifies 3 A, 1.2 N.m, single motor output shaft. | Correct travel candidate, but hold a claim of installation-ready compatibility. Needs four output-hole details, output-face height, mounting nuts, and a qualified power-off restraint. |
| Proposed brake-motor alternative | STEPPERONLINE 23HS30-5004D-B280; dimensions and static brake rating below. | An optional replacement for the supplied Z motor, not a confirmed bolt-on accessory. Reserve its envelope; validate the coupling, flange and retention behavior before purchase/use. |

Sources: [X exact listing](https://www.amazon.com/dp/B0C7GQTRRX),
[Y exact listing](https://www.amazon.com/dp/B0C7GN24S1),
[Z exact listing](https://www.amazon.com/dp/B09MVYGLNQ).
The listing identifies M5 movable nuts on Z; that does not establish the
carriage output fixing-hole thread. The Y/X gallery mentions M3/M4 slot nuts;
it does not give the complete undercut, engagement, insertion and torque data.

## A concrete power-off retention route

The replacement candidate is a two-phase 5 A motor with an integrated power-off
brake: 57 x 57 x 116.5 mm body, diameter8 x21 mm shaft, 15 mm D-flat, brake
2.8 N.m static /24 V /4.5 W. Its body is60.5 mm taller than the original modeled
motor. The manufacturer page displayed **$40.90 goods only, China stock** on this
check; shipping, tax and delivered availability are unverified. Do not add that
amount to a supposed delivered build total.
[Manufacturer product page](https://www.omc-stepperonline.com/nema-23-stepper-motor-2-0nm-283-22oz-in-with-24v-4-5w-electromagnetic-brake-23hs30-5004d-b280).

The CAD reserves the published body envelope at the original flange-plane
assumption and marks it as a replacement candidate. It does **not** claim that
the manufacturer's complete STEP was imported. Its linked technical downloads
could not be retrieved through the available tools. Shaft/pilot/bolt-circle
alignment, coupling bore and engagement require a mating drawing or measurement;
NEMA23 alone does not prove that the complete replacement fits.

The static screen uses an explicitly chosen20 kg moving assembly plus200 N
downward external load and a3.0 design factor. With a5 mm lead and no credit for
screw friction, required holding torque is about0.946 N.m, giving a2.96 ratio
to the stated static brake rating. These are **screening loads**, not a measured
moving mass, a structural load rating or an emergency-stop result. A screw,
coupling or attachment failure is downstream of the motor brake.

The brake must be energized to release only after motor torque is established;
on a normal stop it must engage before drive torque is removed. Abrupt supply
loss still needs the actual brake response time, engagement energy limit,
worst-case drop test with a protected dummy load and suitable independent
support for maintenance. The public static specification does not close these
dynamic questions. The coil needs a separately rated24 V switched circuit;
it is not connected to a motor phase or logic pin. An unloaded500 mA driver
commissioning setting is not a loaded-axis holding qualification.

A counterbalance alone was not substituted: changing between the spindle and
torch changes the suspended load. No cheap spring was assigned a fictitious
force, stroke or failure behavior. The nominal single-ended stock motor is also
not drawn with an imaginary rear shaft for an add-on brake.

## Adapter correction actually implemented

`motion_completion.py` replaces the two unverified carriage slots with a
110 x110 x12.7 mm transfer-drill blank. The four known custom clamp holes and
their rear counterbores remain. All four purchased output-hole positions,
fastener/head dimensions and engagement must come from a recorded measurement
before the generator will produce that pattern. It rejects intersecting head
pockets and insufficient edge material. The guarded blank is not evidence that
the110 mm outline will suit every possible supplier revision.

The adapter's output mounting face is the datum; the current80 mm module stack
still controls an assumed placement in the whole machine. Once measured,
rebuild the head position and recheck actual tool reach. Transfer drilling means
marking centers with the plate aligned and then drilling the removed plate;
never use the purchased guide as a drill fixture with chips entering its rails.

The existing clamp instructions falsely referred to a known diameter28 AG60
torch and parked clamp. That stale statement is removed by the integration
extension. A separate torch-clamp generator takes an explicit measured insulated
barrel diameter, a40 mm usable clamp zone and nozzle offset. It has no diameter
default. It produces a review candidate only; it does not supply the missing
floating touch-off, breakaway, torch body, lead envelope or electrical interface.

## What this closes and what it does not

- Closes the misleading assumed-slot geometry and stale diameter28 torch claim.
- Establishes an actual purchasable brake-motor option with source dimensions,
  published static torque and a bounded screening calculation.
- Does not close Z mounting fasteners, normally engaged retention qualification,
  a real operational plasma head, cable bend/strain relief, supplier load ratings
  or whole-machine rigidity. The9-pose result covers nominal rigid solids only.

## Search boundary

The exact ASIN product pages and their gallery images were checked again.
[KHMOS's manufacturer index](https://www.khmos.com/) identifies HMS40 as a
single-rail ball-screw module. Earlier text calling it a belt module was wrong.
The index was discoverable but direct manufacturer-page retrieval returned403;
the RATTMMOTOR home site was unavailable through the tools. Searches located
third-party ZBX80 CAD and a300 mm manual, but neither was substituted for the
exact supplied100 mm revision. No vendor was contacted.

Historical source evidence remains in
`output/cad-repair-2026-09-25/motion/z-interface-resolution.md` and
`output/release-review/sources/module-gallery-source-manifest.json`.

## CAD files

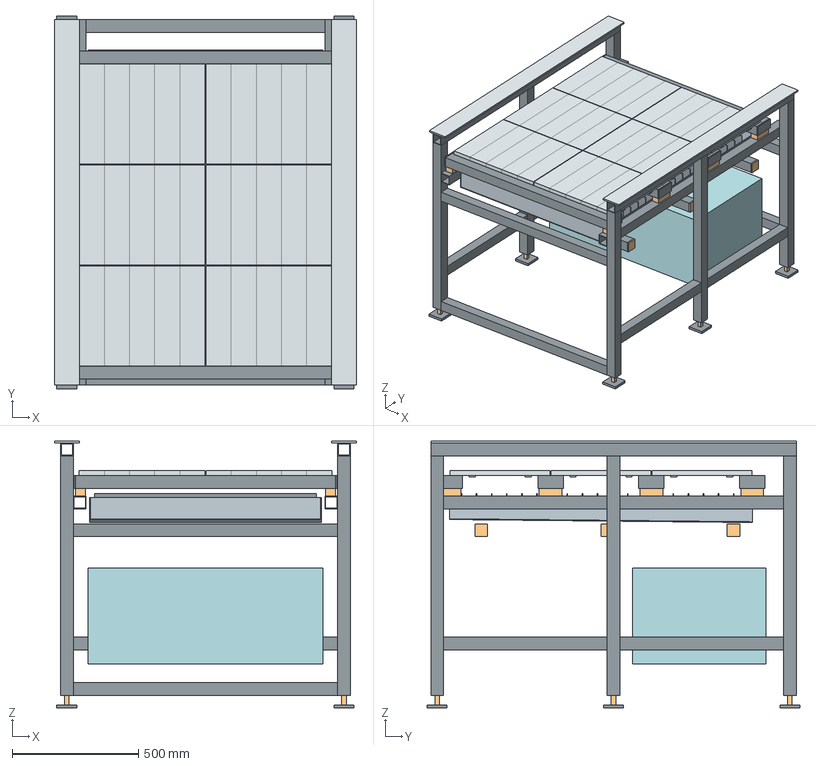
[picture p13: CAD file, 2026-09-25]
output/release-review/RevD-STUDY/step/assembled_bare_extrusion_NOT_RELEASED.step
1199.2 x 1479.2 x 1057.9 mm
MF_LEG_1_1
FOOT_PLATE_1_1
FOOT_ADJUSTER_1_1_ENVELOPE
MF_LEG_1_2
FOOT_PLATE_1_2
FOOT_ADJUSTER_1_2_ENVELOPE
MF_LEG_1_3
FOOT_PLATE_1_3
FOOT_ADJUSTER_1_3_ENVELOPE
MF_TOP_Y_1
MF_LOWER_SIDE_1_1
MF_LOWER_SIDE_1_2
RAIL_CAP_1_BLANK
MF_LEG_2_1
FOOT_PLATE_2_1
FOOT_ADJUSTER_2_1_ENVELOPE
MF_LEG_2_2
FOOT_PLATE_2_2
FOOT_ADJUSTER_2_2_ENVELOPE
MF_LEG_2_3
FOOT_PLATE_2_3
FOOT_ADJUSTER_2_3_ENVELOPE
MF_TOP_Y_2
MF_LOWER_SIDE_2_1
MF_LOWER_SIDE_2_2
RAIL_CAP_2_BLANK
MF_END_FRONT_LOW
MF_END_REAR_LOW
MF_END_FRONT_UPPER
MF_END_REAR_UPPER
MF_RECEIVER_LEDGER_1
MF_RECEIVER_LEDGER_2
PAN_BEARER_1
PAN_BEARER_END_1_1_ENVELOPE
PAN_BEARER_END_1_2_ENVELOPE
PAN_BEARER_2
PAN_BEARER_END_2_1_ENVELOPE
PAN_BEARER_END_2_2_ENVELOPE
PAN_BEARER_3
PAN_BEARER_END_3_1_ENVELOPE
PAN_BEARER_END_3_2_ENVELOPE
PAN_SLOPED_FLOOR
PAN_SIDE_1
PAN_SIDE_2
PAN_END_FRONT
PAN_END_REAR
SLAT_01
SLAT_02
SLAT_03
SLAT_04
SLAT_05
SLAT_06
SLAT_07
SLAT_08
SLAT_09
SLAT_10
SLAT_11
SLAT_12
SLAT_13
SLAT_14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

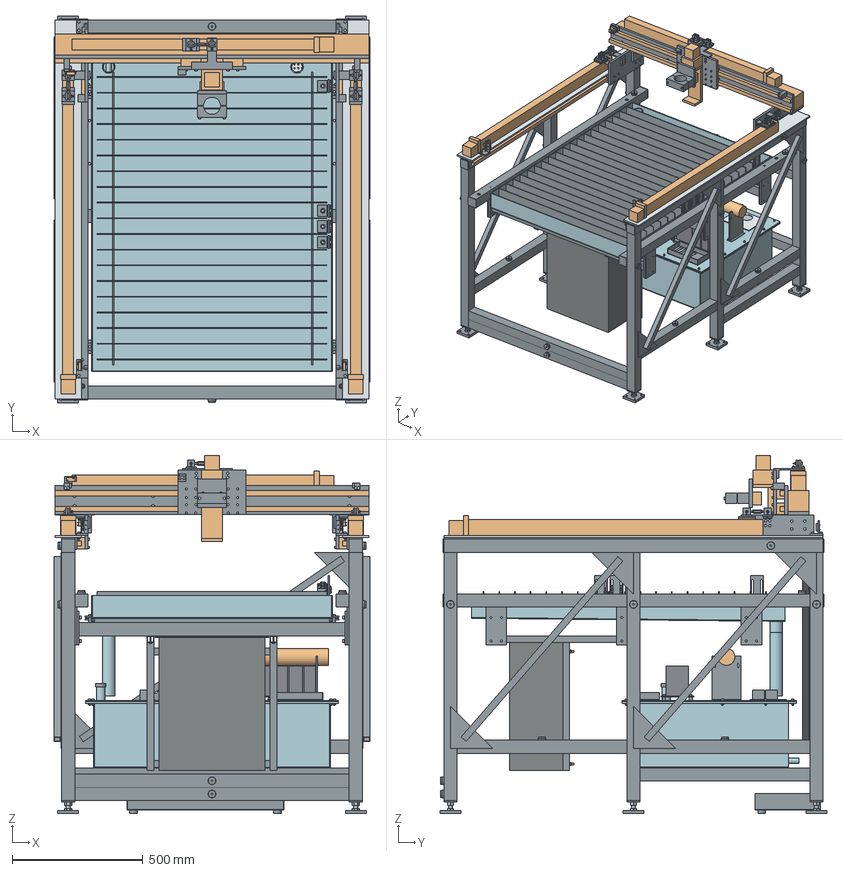
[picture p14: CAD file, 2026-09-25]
output/release-review/RevE-ENGINEERING/step/RevE_PLASMA_SETUP.step
1206.8 x 1479.2 x 1370.0 mm
MF_LEG_1_1
MF_LEG_1_2
MF_LEG_1_3
MF_TOP_Y_1
MF_LOWER_SIDE_1_1
MF_LOWER_SIDE_1_2
RAIL_CAP_1_BLANK
MF_LEG_2_1
MF_LEG_2_2
MF_LEG_2_3
MF_TOP_Y_2
MF_LOWER_SIDE_2_1
MF_LOWER_SIDE_2_2
RAIL_CAP_2_BLANK
MF_END_FRONT_LOW
MF_END_REAR_LOW
MF_END_FRONT_UPPER
MF_END_REAR_UPPER
MF_RECEIVER_LEDGER_1
MF_RECEIVER_LEDGER_2
CAP_SPACER_1
CAP_SPACER_2
FT_1_1_PAD
FT_1_1_LEG_CLOSURE
FT_1_1_UPPER_NUT
FT_1_1_JAM_NUT
FT_1_1_JACK
FT_1_2_PAD
FT_1_2_LEG_CLOSURE
FT_1_2_UPPER_NUT
FT_1_2_JAM_NUT
FT_1_2_JACK
FT_1_3_PAD
FT_1_3_LEG_CLOSURE
FT_1_3_UPPER_NUT
FT_1_3_JAM_NUT
FT_1_3_JACK
FT_2_1_PAD
FT_2_1_LEG_CLOSURE
FT_2_1_UPPER_NUT
FT_2_1_JAM_NUT
FT_2_1_JACK
FT_2_2_PAD
FT_2_2_LEG_CLOSURE
FT_2_2_UPPER_NUT
FT_2_2_JAM_NUT
FT_2_2_JACK
FT_2_3_PAD
FT_2_3_LEG_CLOSURE
FT_2_3_UPPER_NUT
FT_2_3_JAM_NUT
FT_2_3_JACK
FB_SIDE_L_1
FB_GUSSET_L_1_LOW
FB_GUSSET_L_1_HIGH
FB_SIDE_L_2
FB_GUSSET_L_2_LOW
FB_GUSSET_L_2_HIGH
FB_SIDE_R_1
FB_GUSSET_R_1_LOW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

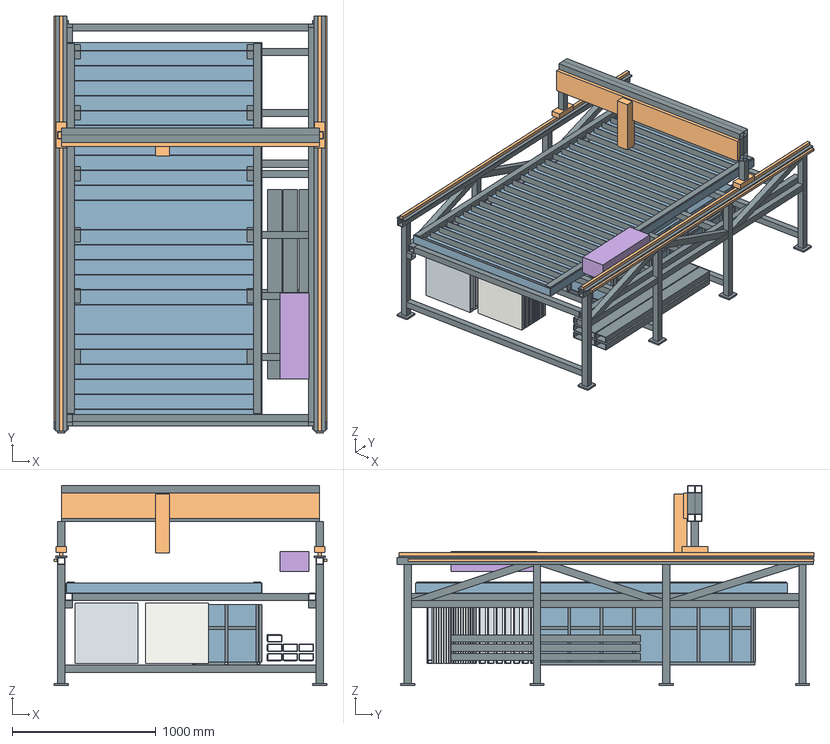
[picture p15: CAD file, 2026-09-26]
variants/48x96/plasma_layout.step
1902.0 x 2905.0 x 1393.5 mm
LEG_L_1
FOOT_L_1
LEG_L_2
FOOT_L_2
LEG_L_3
FOOT_L_3
LEG_L_4
FOOT_L_4
SIDE_L_UPPER
SIDE_L_LOWER_1
SIDE_L_LOWER_2
SIDE_L_LOWER_3
SIDE_L_DIAGONAL_1
SIDE_L_DIAGONAL_2
SIDE_L_DIAGONAL_3
LEG_R_1
FOOT_R_1
LEG_R_2
FOOT_R_2
LEG_R_3
FOOT_R_3
LEG_R_4
FOOT_R_4
SIDE_R_UPPER
SIDE_R_LOWER_1
SIDE_R_LOWER_2
SIDE_R_LOWER_3
SIDE_R_DIAGONAL_1
SIDE_R_DIAGONAL_2
SIDE_R_DIAGONAL_3
PAN_BEARER_L
PAN_BEARER_SEAT_L_0
PAN_BEARER_SEAT_L_1
PAN_BEARER_SEAT_L_2
PAN_BEARER_SEAT_L_3
PAN_BEARER_R
PAN_BEARER_SEAT_R_0
PAN_BEARER_SEAT_R_1
PAN_BEARER_SEAT_R_2
PAN_BEARER_SEAT_R_3
PAN_CROSS_1
PAN_CROSS_2
PAN_CROSS_3
PAN_CROSS_4
PAN_CROSS_5
PAN_CROSS_6
PAN_CROSS_7
LOW_CROSS_1
LOW_CROSS_2
LOW_CROSS_3
LOW_CROSS_4
PAN_FLOOR
PAN_LEFT
PAN_RIGHT
PAN_FRONT
PAN_REAR
SLAT_01
SLAT_02
SLAT_03
SLAT_04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

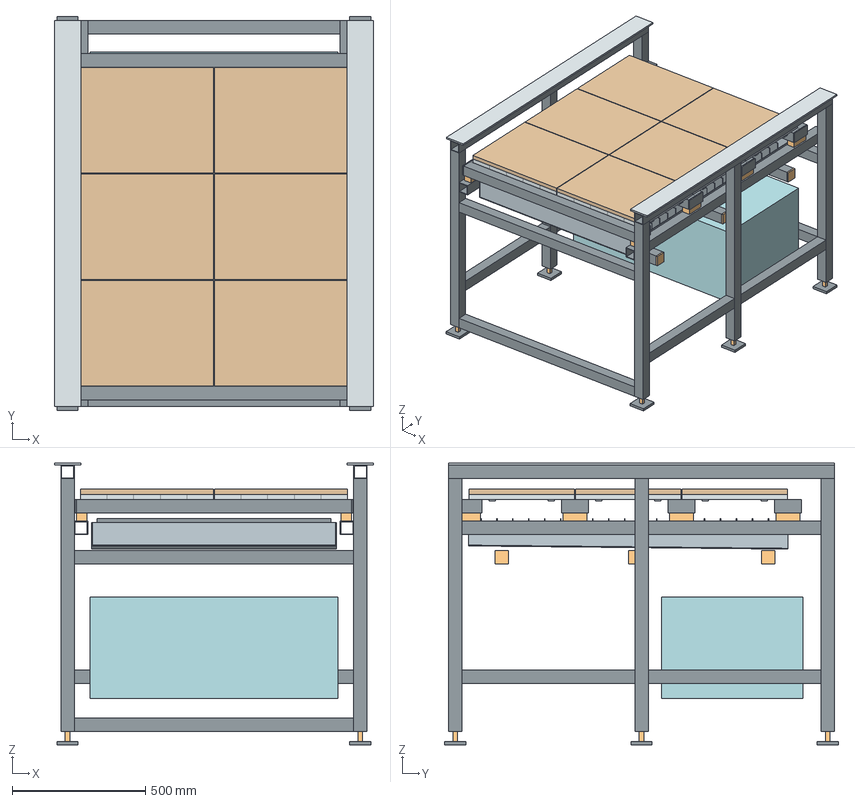
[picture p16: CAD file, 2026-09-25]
output/release-review/RevD-STUDY/step/assembled_with_optional_mdf_NOT_RELEASED.step
1199.2 x 1479.2 x 1057.9 mm
MF_LEG_1_1
FOOT_PLATE_1_1
FOOT_ADJUSTER_1_1_ENVELOPE
MF_LEG_1_2
FOOT_PLATE_1_2
FOOT_ADJUSTER_1_2_ENVELOPE
MF_LEG_1_3
FOOT_PLATE_1_3
FOOT_ADJUSTER_1_3_ENVELOPE
MF_TOP_Y_1
MF_LOWER_SIDE_1_1
MF_LOWER_SIDE_1_2
RAIL_CAP_1_BLANK
MF_LEG_2_1
FOOT_PLATE_2_1
FOOT_ADJUSTER_2_1_ENVELOPE
MF_LEG_2_2
FOOT_PLATE_2_2
FOOT_ADJUSTER_2_2_ENVELOPE
MF_LEG_2_3
FOOT_PLATE_2_3
FOOT_ADJUSTER_2_3_ENVELOPE
MF_TOP_Y_2
MF_LOWER_SIDE_2_1
MF_LOWER_SIDE_2_2
RAIL_CAP_2_BLANK
MF_END_FRONT_LOW
MF_END_REAR_LOW
MF_END_FRONT_UPPER
MF_END_REAR_UPPER
MF_RECEIVER_LEDGER_1
MF_RECEIVER_LEDGER_2
PAN_BEARER_1
PAN_BEARER_END_1_1_ENVELOPE
PAN_BEARER_END_1_2_ENVELOPE
PAN_BEARER_2
PAN_BEARER_END_2_1_ENVELOPE
PAN_BEARER_END_2_2_ENVELOPE
PAN_BEARER_3
PAN_BEARER_END_3_1_ENVELOPE
PAN_BEARER_END_3_2_ENVELOPE
PAN_SLOPED_FLOOR
PAN_SIDE_1
PAN_SIDE_2
PAN_END_FRONT
PAN_END_REAR
SLAT_01
SLAT_02
SLAT_03
SLAT_04
SLAT_05
SLAT_06
SLAT_07
SLAT_08
SLAT_09
SLAT_10
SLAT_11
SLAT_12
SLAT_13
SLAT_14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

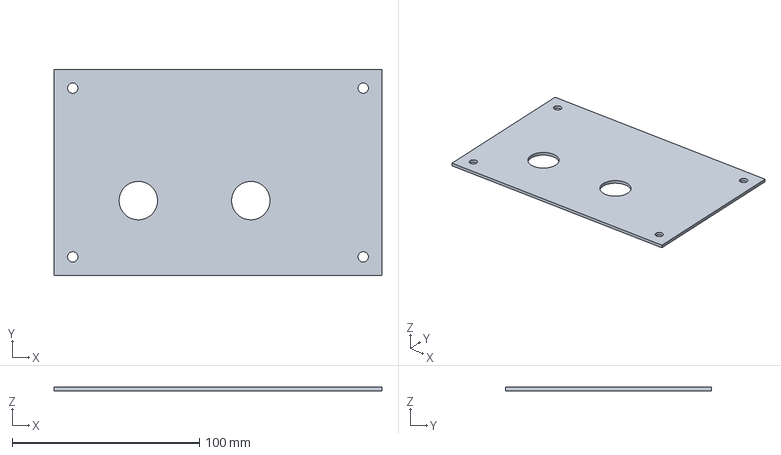
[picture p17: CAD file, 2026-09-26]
output/release-review/RevI-CAD/parts/I_CAB_GLAND_MAINS.step
175.0 x 110.0 x 2.00 mm

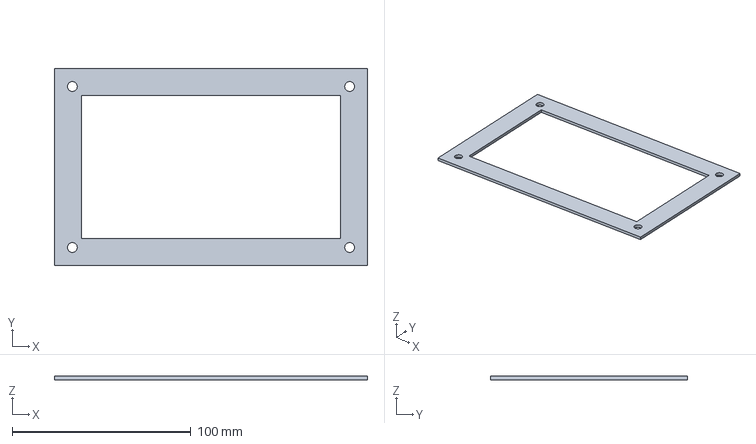
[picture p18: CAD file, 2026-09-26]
output/release-review/RevI-CAD/parts/I_CAB_GLAND_GASKET_MAINS.step
175.0 x 110.0 x 2.00 mm

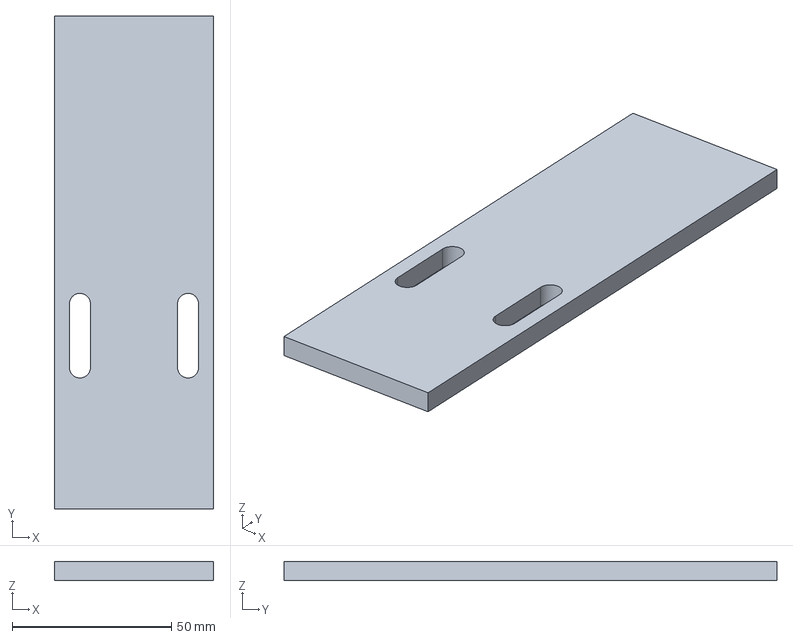
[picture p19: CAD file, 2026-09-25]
output/cad-repair-2026-09-25/frame/FLOAT_BACKRAIL_PAN_EMPTY.step
50.0 x 155.0 x 6.00 mm

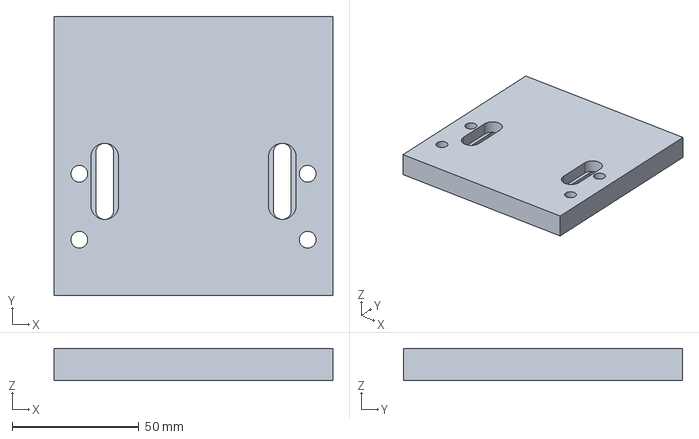
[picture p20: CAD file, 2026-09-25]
output/cad-repair-2026-09-25/motion/TOOL_ADAPTER_110.PROVISIONAL.step
110.0 x 110.0 x 12.7 mm

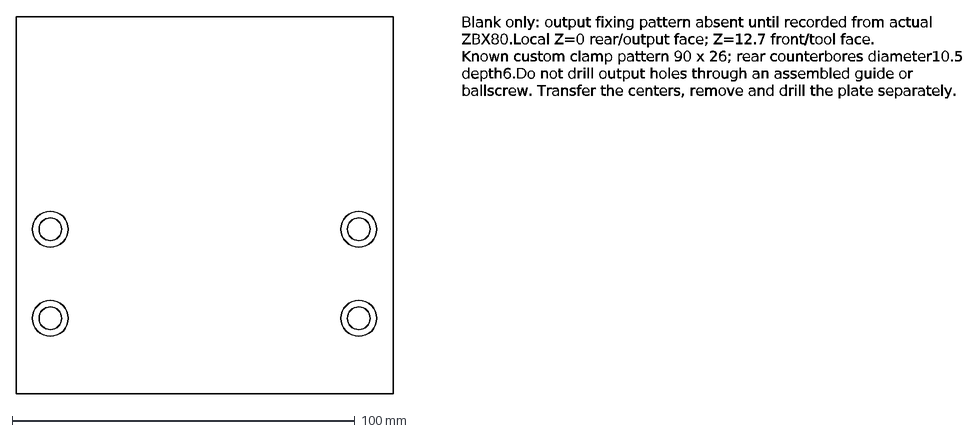
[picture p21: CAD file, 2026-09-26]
output/design-completion-2026-09-26/motion/adapter-transfer-blank.dxf
Blank only: output fixing pattern absent until recorded from actual ZBX80. Local Z=0 rear/output face; Z=12.7 front/tool face. Known custom clamp pattern 90 x 2

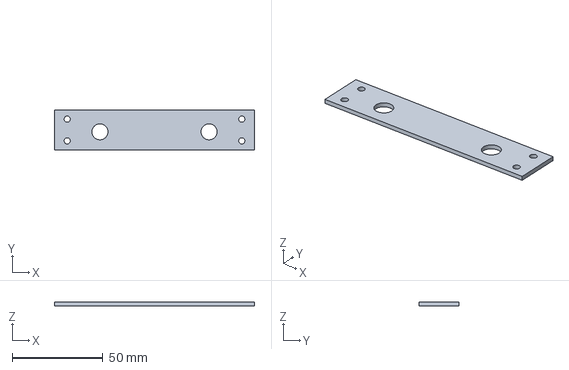
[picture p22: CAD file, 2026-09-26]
output/design-finish-2026-09-26/motion/head-cad/parts/I_HEAD_BEARING_CAP_1.step
110.0 x 22.0 x 2.00 mm

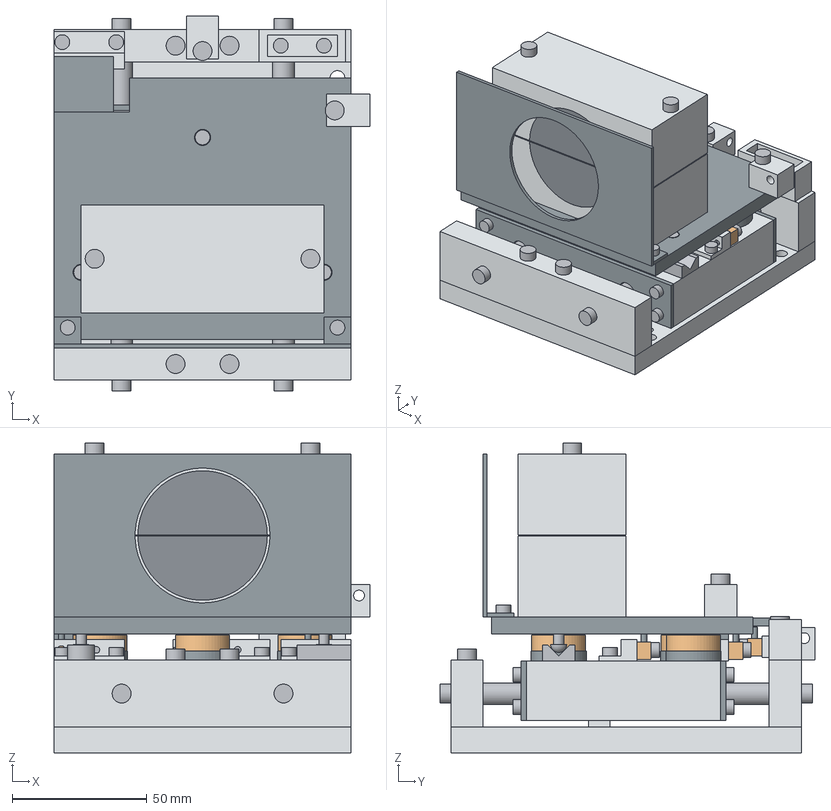
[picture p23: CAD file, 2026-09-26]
output/design-finish-2026-09-26/motion/head-cad/step/RevI_FLOAT_BREAKAWAY_HEAD_BLANK.step
117.0 x 139.0 x 114.8 mm
I_HEAD_BACKPLATE
I_HEAD_CROSSBAR_1
I_HEAD_BAR_1_45
I_HEAD_BAR_1_65
I_HEAD_CROSSBAR_2
I_HEAD_BAR_2_45
I_HEAD_BAR_2_65
I_HEAD_ROD_25
I_HEAD_ROD_TOP_25
I_HEAD_ROD_BOTTOM_25
I_HEAD_ROD_85
I_HEAD_ROD_TOP_85
I_HEAD_ROD_BOTTOM_85
I_HEAD_FLOAT_CARRIAGE
I_HEAD_BUSH_25_28
I_HEAD_BUSH_25_75.85
I_HEAD_BUSH_SPACER_25
I_HEAD_BUSH_85_28
I_HEAD_BUSH_85_75.85
I_HEAD_BUSH_SPACER_85
I_HEAD_BEARING_CAP_1
I_HEAD_CAP_1_7_17
I_HEAD_CAP_1_7_29
I_HEAD_CAP_1_103_17
I_HEAD_CAP_1_103_29
I_HEAD_BEARING_CAP_2
I_HEAD_CAP_2_7_17
I_HEAD_CAP_2_7_29
I_HEAD_CAP_2_103_17
I_HEAD_CAP_2_103_29
I_HEAD_FLOAT_STOP
I_HEAD_STOP_49
I_HEAD_STOP_61
I_HEAD_SEAT_CONE
I_HEAD_BUTTON_CONE
I_HEAD_SEAT_V
I_HEAD_BUTTON_V
I_HEAD_SEAT_FLAT
I_HEAD_BUTTON_FLAT
I_HEAD_RELEASE_PLATE
I_HEAD_BUTTON_SCREW_CONE
I_HEAD_BUTTON_SCREW_V
I_HEAD_BUTTON_SCREW_FLAT
I_HEAD_MAGNET_SPACER_1
I_HEAD_MAGNET_1
I_HEAD_MAGNET_SCREW_1
I_HEAD_MAGNET_SPACER_2
I_HEAD_MAGNET_2
I_HEAD_MAGNET_SCREW_2
I_HEAD_MAGNET_SPACER_3
I_HEAD_MAGNET_3
I_HEAD_MAGNET_SCREW_3
I_HEAD_CLAMP_REAR
I_HEAD_CLAMP_FRONT
I_HEAD_CLAMP_MOUNT_25_35
I_HEAD_CLAMP_MOUNT_25_55
I_HEAD_CLAMP_MOUNT_85_35
I_HEAD_CLAMP_MOUNT_85_55
I_HEAD_CLAMP_PINCH_15
I_HEAD_CLAMP_PINCH_95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

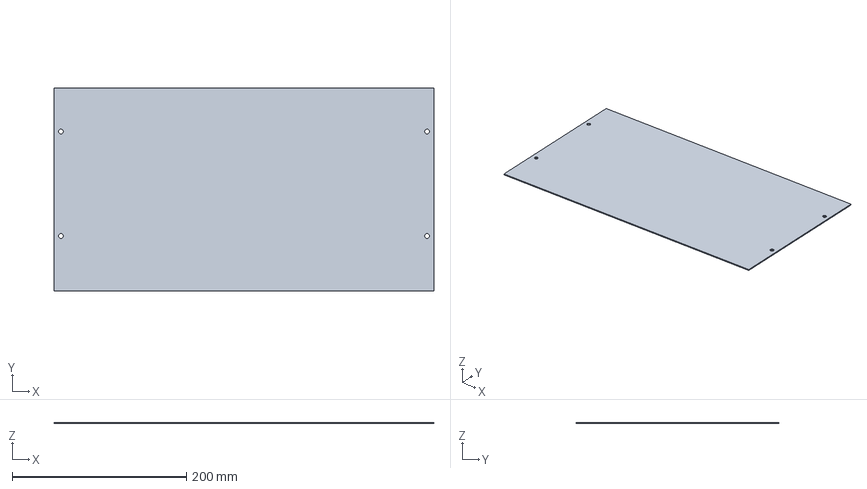
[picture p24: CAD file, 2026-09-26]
output/release-review/RevI-CAD/parts/CAB_DRIP_CAP.step
436.4 x 233.2 x 1.50 mm

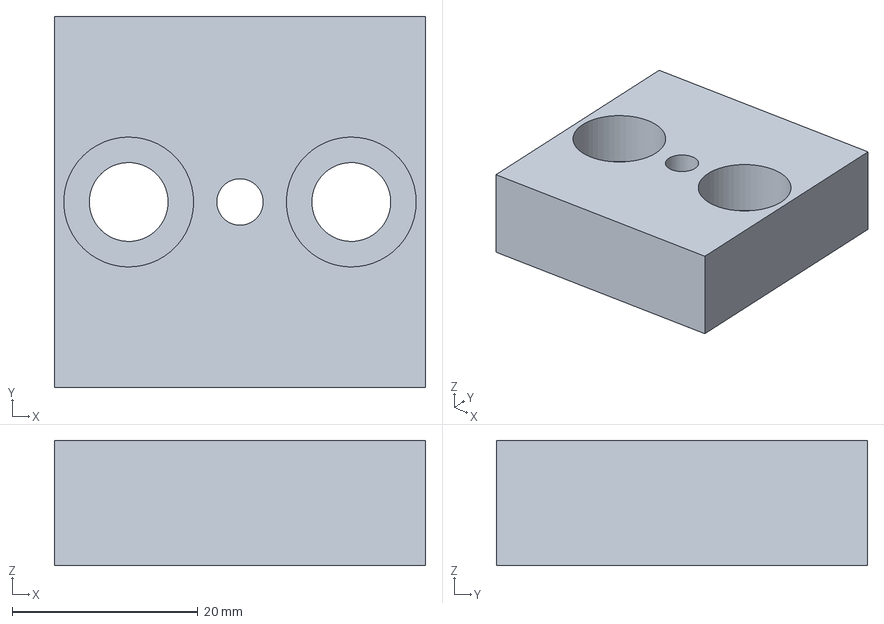
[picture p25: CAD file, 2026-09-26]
variants/common/location/output/parts/LOC_Z_SUPPLEMENTARY.step
40.0 x 40.0 x 13.5 mm

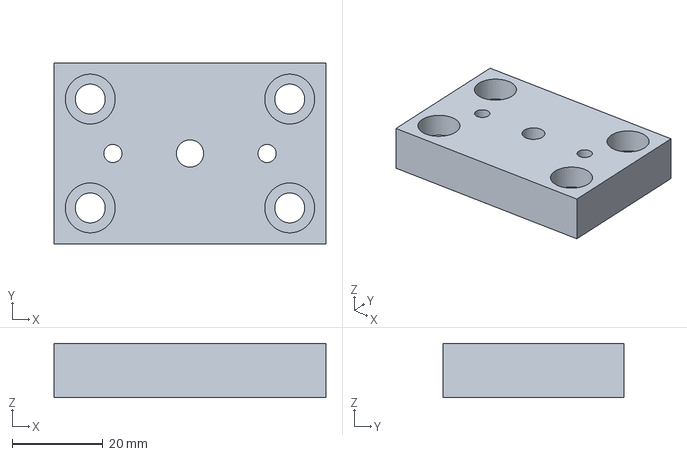
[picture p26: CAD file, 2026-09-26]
variants/common/location/output/protected/parts/LOC_PIN_BLOCK_60_40_12_CB_M6.step
60.0 x 40.0 x 12.0 mm

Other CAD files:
output/release-review/RevI-CAD/nesting/carbon_steel_6.35mm_sheet_01.dxf
variants/48x96/router.step
variants/common/location/output/protected/step/common-locator-protected.step
variants/common/location/output/step/common-locator-dock.step
output/cad-repair-2026-09-25/frame/CAB_CAP_TAB_LEFT.dxf
output/cad-repair-2026-09-25/frame/CAB_CAP_TAB_LEFT.step
output/cad-repair-2026-09-25/frame/CAB_CAP_TAB_RIGHT.dxf
output/cad-repair-2026-09-25/frame/CAB_CAP_TAB_RIGHT.step
output/cad-repair-2026-09-25/frame/CAB_DRIP_CAP.dxf
output/cad-repair-2026-09-25/frame/CAB_DRIP_CAP.step
output/cad-repair-2026-09-25/frame/CAB_DRIP_FRONT_LIP.dxf
output/cad-repair-2026-09-25/frame/CAB_DRIP_FRONT_LIP.step
output/cad-repair-2026-09-25/frame/CAB_STRINGER_1.step
output/cad-repair-2026-09-25/frame/CAB_STRINGER_2.step
output/cad-repair-2026-09-25/frame/FLOAT_BACKRAIL_PAN_EMPTY.dxf
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

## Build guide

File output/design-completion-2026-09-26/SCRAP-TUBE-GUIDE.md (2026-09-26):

# Scrap-yard tube guide — current chassis

Use this to choose usable material. Rev H retains the Rev G 2-inch tube blank lengths; leave scrap stock long until its actual dimensions and condition are checked against the final cutting plan.

**Section:** nominal 2 x 2 inch mild-steel square tube, 0.120 inch wall in the CAD (roughly 1/8 inch). Scrap material has no assumed ASTM grade or remaining-wall guarantee. Measure clean metal at multiple accessible places; paint and rust do not count as wall thickness. Straightness, sound corners and intact wall matter at least as much as outside size.

## Current lengths

| Quantity | Finished blank, mm | Finished blank, inches | Convenient minimum rough piece |
|---:|---:|---:|---:|
| 4 | 1450 | 57.087 | 58 inches |
| 7 | 1048.4 | 41.276 | 42 inches |
| 3 | 1016.4 | 40.016 | 41 inches |
| 6 | 949.2 | 37.370 | 38 inches |
| 4 | 924 | 36.378 | 37 inches |
| 6 | 648.8 | 25.543 | 26 inches |

Total: 30 blanks, 96.69 feet finished. Five full 20-foot sticks fit the present schedule with a 3 mm saw kerf and 10 mm trim per stick. Random scrap lengths need a different nesting plan; equal total footage does not guarantee the cuts fit.

Prioritize four sound pieces at least 58 inches long for the top rails and bed ledgers. Keeping longer stock intact usually gives more nesting choices. Do not splice the top rails or bed beams merely to recover short scrap without a designed joint.

Set aside pieces with deep pitting, holes, buckles, split seams or damaged corners. Surface rust can be cleaned for inspection, but hidden internal corrosion cannot be accepted from appearance alone. Old welded attachments must leave sufficient sound length after removal. Unknown scrap strength and wall condition remain material-verification requirements; the new-stock calculations do not certify scrap.

**Send back:** number of pieces, usable lengths after damaged ends, measured wall thickness, and price. Record the longest straight, undamaged segment in each piece. Do not infer wall thickness from the outside 2-inch dimension.

## Scope and references

This list covers only modeled 2-inch square tubing. The design also uses 1-inch braces, plates, pan/tank sheet, rails and hardware. Sand adds mass/damping; it is not credited as a substitute for steel section or straight mounting datums. Weld and drill before filling any tube.

[Current cut schedule](../release-review/RevH-CAD/TUBE-CUT-PLAN.md). The [Steel Tube Institute ASTM A500 explanation](https://steeltubeinstitute.org/resources/astm-a500/) distinguishes nominal wall thickness from design thickness; its certified-new-material assumptions do not identify or qualify unmarked scrap.

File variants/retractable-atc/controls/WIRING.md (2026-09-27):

# Retractable dock terminal and circuit definition

This candidate circuit is allocated to the large-machine 164 mm shutter profile. The small-machine automatic profile is unavailable until its actual cover/closure mechanism and feedback are integrated; unused signals must never be simulated to satisfy this circuit.
This is a low-voltage schematic candidate, not a finished PCB or installation release. All numbers prefixed **XA** are new panel terminals. Manufacturer contact and IC pin numbers are identified separately. [io_plan.json](io_plan.json) is the machine-readable allocation. The existing [run circuit](../../../output/design-finish-2026-09-26/controls/RUN-INTERFACE.md) stays independent; no sensor or software output bridges its stop contacts.

## Supply domains and connector pinning

**LOGIC3V3/LOGIC0** come from the Kraken logic supply; J22 SWD pin 1 is 3.3 V and pin 3 is ground in the referenced board schematic. Verify actual V1.1 labels before connection. **C24V/FIELD0** are the existing isolated 24 V control supply, screened here over 21.6–26.4 V. **AUX24_SAFE** is a separately fused actuator feed removed by the hardware auxiliary stop/power system. Its contactor design is not invented here. Never power added coils from HEAD_SAFE or the PhotoMOS head loop.

P10 I2C: **1 = 5 V (leave disconnected), 2 = LOGIC0, 3 = PB10 SCL, 4 = PB11 SDA**. BTT shows 4.7 kΩ pull-ups from SCL/SDA to 3.3 V. Keep the expander in the control cabinet, short wiring, 100 kHz; no moving I2C cable. Verify rise time on the actual bus. The schematic supplied locally is V1.0; the official common V1.0/V1.1 mapping supports these signals but actual V1.1 header orientation still needs continuity checks. [BTT primary files](https://github.com/bigtreetech/BIGTREETECH-Kraken).

U_IO is **MCP23017-E/SP, 28-pin SPDIP**: pin 9 = LOGIC3V3, pin 10 = LOGIC0, pin 12 = SCL, pin 13 = SDA. Pins 15/16/17 to LOGIC0 give address 0x20. Pin 18 RESET gets 10 kΩ to 3V3 and a controller-reset connection only after electrical validation; initial design permits a manual reset switch to LOGIC0 with required≥1 µs low. Add 100 nF X7R directly 9–10 and 1 µF nearby. Pins 11/14 are NC; 19/20 interrupt outputs unconnected. Pins 8/28 (GPB7/GPA7) are explicitly unused output-low. **They must not be sensor inputs**: [Microchip RevD](https://ww1.microchip.com/downloads/aemDocuments/documents/APID/ProductDocuments/DataSheets/MCP23017-Data-Sheet-DS20001952.pdf) corrects the older RevC limitation. All fourteen remaining pins are inputs; no interrupt lines are added.

## Fourteen isolated inputs: eight dry-contact channels and six PNP channels

The four slide/shutter endpoint channels and four unselected VFD/kit channels use two-wire **dry contact** loops. Pin sensors use the separate PNP circuit below. For a dry-contact channel:

`C24V -> F_INPUT(0.25A) -> 3.32kΩ 1% 0.6W -> XA:odd -> NO confirmation contact -> XA:even -> AQY212GS LED pin1; LED pin2 -> FIELD0.`

Across LED1–2 fit 22 kΩ, 1% and a 1N4148 with cathode at LED1. The current-limiting resistor is before the outgoing field conductor. On the isolated logic side: `LOGIC3V3 ->4.7kΩ1% -> GPIO node ->330Ω1% -> AQY pin4; AQY pin3 ->LOGIC0`. Add 4.7 nF C0G from GPIO node to LOGIC0. The output is a floating NO PhotoMOS contact; neither field return nor cable shield connects to LOGIC0. Closed confirmation pulls logic LOW. Open wire/power loss reads HIGH/unconfirmed. [Panasonic](https://industry.panasonic.com/ac/cdn/e/control/relay/photomos/catalog/semi_eng_gu1a_aqy21_gs.pdf), [Omron switch data](https://omronfs.omron.com/en_US/ecb/products/pdf/en-d2hw.pdf).

| XA pair | Feedback | MCP pin |
|---|---|---|
|1–2|Park endpoint|GPA0 /21|
|3–4|Deployed endpoint|GPA1 /22|
|5–6|Park pin fully extended|GPA2 /23|
|7–8|Park pin fully retracted|GPA3 /24|
|9–10|Deployed pin fully extended|GPA4 /25|
|11–12|Deployed pin fully retracted|GPA5 /26|
|13–14|Outer shutter fully open|GPA6 /27|
|15–16|Outer shutter fully closed|GPB0 /1|
|17–18|Shutter catch pin extended|GPB1 /2|
|19–20|Shutter catch pin retracted|GPB2 /3|
|21–22|Spindle stopped feedback|GPB3 /4|
|23–24|Spindle running feedback|GPB4 /5|
|25–26|Kit internal cover open|GPB5 /6|
|27–28|Kit internal cover closed|GPB6 /7|

The **four slide/shutter endpoint contacts** can use Omron **D2HW-C203MR**, black COM / blue NO, subject to actual brackets, cams and overtravel. Their published small-load reference is 5 V / 1 mA; the dry loop supplies about 5.57–8.12 mA including a 1 V low-supply wiring/contact-drop allowance.

The **six pin endpoint sensors** are separate **Panasonic PM-U25-P** units. Use one independent sensor and flag per endpoint, not the complementary outputs of one sensor. Brown receives fused C24V; blue returns to FIELD0; white is the Dark-ON confirmation output. Insulate unused black Light-ON separately. For each PNP channel use this circuit instead of the dry loop:

`C24V -> F_INPUT -> XA:odd -> sensor brown; sensor white -> XA:even -> 3.32 kΩ -> AQY LED pin 1; sensor blue -> dedicated return terminal -> FIELD0.`

The LED shunt, reverse diode and isolated logic circuit remain the same. In the PNP channels the 3.32 kΩ resistor is **after the white return**, not in the brown supply. No 24 V conductor connects to an MCP or MCU pin.

| Pin endpoint | Brown supply | White Dark-ON return | Blue FIELD0 return |
|---|---|---|---|
| Park pin extended | XA5 | XA6 | XA41 |
| Park pin retracted | XA7 | XA8 | XA42 |
| Deployed pin extended | XA9 | XA10 | XA43 |
| Deployed pin retracted | XA11 | XA12 | XA44 |
| Shutter catch extended | XA17 | XA18 | XA45 |
| Shutter catch retracted | XA19 | XA20 | XA46 |

The PNP output's maximum 1 V residual at 16 mA plus the separate 1 V wiring allowance leaves **at least 5.276 mA** calculated AQY LED current at 21.6 V. The maximum load remains below 8.12 mA, inside that residual-voltage reference point. Add **six × 15 mA = 90 mA** sensor quiescent current to the field load; this published consumption includes the sensor's built-in indicator. No extra field indicators are selected. The retrieved catalog does not establish a worst-case output-off leakage bound: verify an unblocked slot produces AQY LED current below 0.1 mA at the actual temperature/supply before commissioning. Do not infer a guaranteed off margin from the powered-on calculation. [Panasonic catalog](https://industry.panasonic.com/ac/e_download/fasys/sensor/micro/catalog/pm-254565_e_cata.pdf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), [selected sensor record](../hardware/PIN-SENSORS.md).

Both endpoint indications cannot legitimately be true together. Combine the **correct slide endpoint plus its matching pin** for engagement; inactive pins can extend in free air. Sensor flags must correspond to full pin travel. A fouled or blocked optical slot can falsely indicate an endpoint: guarded placement, inspection and the opposing independent sensor/travel checks are required. This installation has no safety performance claim. The selected sensor is a procurement candidate; observed backorder/price data do not establish availability or delivered cost.

The final four channels are electrically defined **only for verified isolated dry contacts**. The actual VFD and kit have not been identified; do not connect a24 V/5 V/PNP/NPN signal directly to this loop, and do not jumper a missing feedback. A drive's “run command accepted” is not necessarily running or standstill feedback. The exact meanings, thresholds, delay and fault behavior must be documented. Existing PG7 IR,PG8 toolsetter andPF10 presence also retain their separate unresolved isolation interfaces. They are not fabricated contacts on this expander.

## Three isolated command channels

For PE13,PE14 and PD10 use separate identical stages:

`GPIO ->1k -> SN74LVC1G17DBVR pin2`, with 10k from pin 2 to LOGIC0. Buffer pin 5 = 3V3, pin 3 = LOGIC0, pin 1 = NC;100 nF across 5–3. Pin 4 ->154 Ω1%0.25 W ->AQY212GS LED1;LED2 = LOGIC0;22k acrossLED1–2. Output AQY pin 4 = AUX24_SAFE through0.25 A control fuse;AQY pin 3 = relay A1;relay A2 = FIELD0. Fit 1N4007 directly across each relay coil, cathode at A1. PD10 is J14 pin 2 through the board's 100 Ω resistor; J14 pin 1 is LOGIC0; the buffer pull-down still provides an off state. Each PhotoMOS drives **only one ≤40 mA relay coil**, never a solenoid. [TI pinout](https://www.ti.com/lit/ds/symlink/sn74lvc1g17.pdf), [Finder contacts/coil/socket](https://cdn.findernet.com/app/uploads/S40EN.pdf).

| Command | Relay and socket | Contact wiring |
|---|---|---|
|PE13, active HIGH releases both rack pins|K_RACK_RELEASE, 40.52.9.024.0000 / 95.05|AUX24_SAFE -> 11, NO 14 branches through independent 1 A fuses to XA31 and XA33|
|PE14, active HIGH releases shutter catch|K_SHUTTER_RELEASE, 40.52.9.024.0000 / 95.05|AUX24_SAFE -> 11, NO 14 ->independent 1 A fuse -> XA35|
|PD10, active HIGH permits original run-arm chain|K_ATC_GATE, 40.52.9.024.5000 gold / 95.05|Existing XW34 -> XA39 -> 11; NO 14 -> XA40 -> existing PERMIT|

**Remove the old direct XW34–PERMIT link when inserting K_ATC_GATE; never leave a parallel bypass.** This places the added contact upstream of both K_RUN_ARM's pickup/hold branches and its tool-request pole. Losing the ATC gate drops run-arm as well as selected-tool permission. K_REQUEST remains independently supplied as in the baseline, so a held-high run request cannot re-arm. Existing PG6 readiness is upstream and does not prove this added relay contact closed. The additional contact is ordinary control, not a monitored safety relay; a welded contact is not detected here.

**Relay timing handoff:** K_ATC_GATE opening drops K_RUN_ARM on every conversion. After restoring the gate, keep PG2 LOW for a measured, qualified release-to-rearm interval covering both K_ATC_GATE closing and K_RUN_ARM pickup. The future M6 adapter must enforce this before the first spindle request or toolpath action. The offline TOOL permission is immediate and does not simulate relay pickup; PG6 is not gate/run-arm feedback. Do not bypass the request-release interlock to cure a timing race.

XA31/32 = park solenoid+/return; 33/34 = deployed solenoid+/return; 35/36 = shutter solenoid+/return. XA32/34/36 = FIELD0. Each coil is Delta **DSOL-1151-24C** with its own local **1N5408**, cathode at positive, anode at return. Separate coil branches avoid interpreting a shared fuse as individual protection. The relay sees up to 1 A combined design allocation for the two rack coils; shutter allocation 0.5 A. Unused relay poles 21/22/24 are insulated and unconnected. XA29/30 = C24V/FIELD0 input-board supply; XA37/38 = AUX24_SAFE/FIELD0 actuator feed. All field terminals may use Phoenix PT 2,5/3209510 with appropriate end plates and rail restraints, consistent with the earlier panel selection.

The Delta sheet specifies 24 V, 7.5 W, 100% duty, 76.8 Ω±10% at 25°C but also lists 0.4 A. Use at least 0.4 A per coil; this candidate budgets 0.5 A each. [Hardware source and qualification](../hardware/LOCK-ACTUATOR.md) records that discrepancy and the unqualified pull force. A 0°C copper-resistance screen gives about 0.424 A at 26.4 V, but it is not a guaranteed cold-winding limit. The 1 A fuses are candidate branch protection; verify DC interrupt rating, actual supply fault current, wire ampacity and coil data. Design allocation for all three coils, three relay coils, 14 input loads and six sensor quiescent loads is about 1.824 A on 24 V, excluding both stepper motor supplies and the actual kit. Flyback diodes slow spring return; measured de-energize/engage time is required. [Vishay 1N5408](https://www.vishay.com/docs/88516/1n5400.pdf).

The same independently sensed catch must engage at either stopped shutter detent. Before parked run permission, the model explicitly waits in CAPTURE_SHUTTER_CLOSED for extended/not-retracted feedback; simply seeing the closed endpoint is insufficient.

## Motor and firmware boundary

Wire each verified winding pair to its corresponding S5/S6 A1/A2 and B1/B2 terminals, with strain relief and shield bonding at cabinet PE. Identify pairs by the delivered motor's drawing and resistance measurement; the old 17E19S1684MB sheet and newer MB4 variants have different documented lead colors, so this document does not guess a color translation. Never connect/disconnect a motor while energized. No external stepper driver is added.

S5/S6 share SPI with existing axes. The future scheduler must serialize configuration/register transactions, keep S7/S8 chip-selects and enables inactive, use 75 mΩ per auxiliary channel and stop pulses on failed health/readback. The current firmware's board initialization intentionally sets S5/S6 disabled: this candidate is not runnable by wiring alone. Independent watchdog/fault responses and the actual motor-power stop arrangement remain untested. A 200 mm nominal pulse count or a limit switch is not a proven mechanical travel boundary.

## Additional component count for the large-machine candidate

- 1 MCP23017-E/SP; 14 AQY212GS input channels; 3 AQY212GS output channels; 3 SN74LVC1G17DBVR buffers.
- 2 Finder40.52.9.024.0000, 1 Finder40.52.9.024.5000, 3 Finder95.05 sockets; 3 Delta release coils; 3 local 1N5408 and 3 relay 1N4007 diodes.
- 4 selected mechanical endpoint switches, 6 PM-U25-P pin sensors, and 4 unselected external dry-contact interfaces; the existing IR/toolsetter/presence interfaces are additional.
- 46 new XA terminal positions, 3 individual 1 A coil fuse branches plus separately protected control/input feeds; the exact fuse/holder SKUs and final harness remain open.

This count does not include the actual magazine, its cover electronics, or the two separately selected screw motors. No delivered-price total or hardware qualification follows from the arithmetic screen.

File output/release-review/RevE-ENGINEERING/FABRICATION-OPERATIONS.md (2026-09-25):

# Fabrication operations for the Rev F solid model

All dimensions are millimeters. The STEP geometry and `part-operations.json` distinguish custom parts from purchased clearance envelopes. The files are an engineering definition; purchased interfaces marked **GUARDED** are not released for fabrication.

## Stock and datums

- Main tubes are nominal 2 × 2 × 0.120 inch steel: 50.8 mm outside and 3.048 mm wall. Square tube corners in the model are idealized; do not treat an unmachined tube face as a precision rail datum.
- Braces use 1 × 1 × 0.083 inch tube: 25.4 mm outside and 2.1082 mm wall.
- Custom 6, 8 and 12 mm plate dimensions remain metric. Finish 6 mm from 1/4 inch stock, 8 mm from 3/8 inch stock, and 12 mm from 1/2 inch stock. Do not substitute a thinner imperial plate without updating the adjoining datums.
- Module rails are 2 × 2 × 0.120 at 1290 mm; crossmembers are 2 × 1.5 × 0.120 laid flat at 938.4 mm. Rail caps use actual 5/16 inch thickness, 7.9375 mm. The MDF sub-bed is two layers of 1/2 inch (12.7 mm); spoilboards finish 3/4 inch stock to 19 mm.
- Module rail tops are Z890.8 on the Z840 ledgers; crossmember tops Z895.4; surfaced MDF top nominal Z920.8; the aluminum deck is Z940.8; the 19 mm spoilboard is Z959.8. Plasma slats are Z850. Raised rail-cap tops are Z1063.9375. There are no ground receiver faces in Rev F: the in-machine MDF surfacing pass replaces that datum work.

## Reading the DXFs

`CUT_OUTER`, `CUT_HOLES` and `CUT_INNER` define through-cut geometry. Layers beginning `MILL_` or `CSK_` identify secondary machining and must not be included in a through-cut laser program. `MACHINING_NOTES` gives the machining side, depth and thread callouts.

The pan-bearer hanger STEP uses an 8 mm nominal thread envelope. Its DXF correctly uses a **6.8 mm pilot**, followed by **M8 × 1.25 through tapping**. Other guarded supplier mating patterns must be measured or sourced before drilling. A generic drawing file is not machine-specific CAM or G-code.

Some compound guard notches are issued as individual STEP solids only. Use their local solid geometry and part notes to create the sheet layout; no ambiguous overlapping through-cut contours are supplied.

## Machined details

- Foot pads: 80 × 80 × 12.7 mm, four 9 mm anchor holes and a central 32 mm diameter pocket **2 mm deep from the top**. Floor-anchor selection is site-specific.
- Drawdown sleeves: 18 mm outside diameter, 9 mm bore, 50.8 mm length, four total, welded through both rail walls and finished flush both faces. No counterbore: the M8 × 70 head seats on the rail top outside the deck plan.
- Lift ears: four 6 mm plates, 50.8 × 100 mm outline with Ø16 hole at 75 mm; continuous 3 mm weld around the rail end perimeter.
- MDF layers: Ø5.5/Ø5.7 through holes per the DXF; lower layer takes Ø16 × 6 underside pockets at the fifty deck-screw stations, upper layer takes Ø12 × 6 top pockets at the sixteen frame-screw stations. Surface the assembled top 1.0 mm nominal IN THE MACHINE after the frame screws are torqued.
- Deck strips: ONE saw cut to 1197 mm. No drilling, no keyholes, no tie-bar slots. Fifty M5 × 25 ISO 7380 button screws with Ø15 fender washers enter from below into DIN 562 bottom-slot square nuts.
- Spoilboards: one left and one right, 465.6 × 1197 × 19 mm from a single 1220 × 2440 sheet. The X 108–1039.2 trim is a hoist-clearance requirement; do not substitute full-width boards.
- Spoilboard screws: M5 × 20 DIN 7991 into DIN 562 top-slot nuts. Counterbore 10 mm diameter × 3 mm, then countersink a further 2.25 mm at 90 degrees. Heads sit 3 mm below the initial board surface. Limit routine surfacing to 2 mm before resetting or replacing the board.
- Sand plugs: M20 × 1.5 threaded shank, 10 mm long; 28 mm diameter × 6 mm head with a 6 mm hex socket, 4 mm deep. The mating bung is 30 mm outside diameter × 10 mm long; drill 18.5 mm before tapping M20 × 1.5.

## Assembly and verification

Complete welding and coating before adding dry ballast. Do not weld a filled tube. Measure actual ballast mass rather than assuming complete packing. The ledger fill ports sit at Y1370, behind the module rail span. Seal the MDF edges and underside after the surfacing pass; the top face stays bare under the aluminum.

The pan has a 1% rearward slope. Its cradle webs follow that slope; fit them without pulling the pan out of shape. Weld and water-test the pan and reservoir before installing controls. The reservoir is permanently vented and must never be connected to compressor pressure or vacuum.

Float carriers have adjustable mounting slots and removable guards. Their modeled mounting heights are initial settings, not the electrical trip planes. Wet-calibrate minimum, normal, high-high and reservoir-low levels. The low pan sensor plus timed draining does not prove a perfectly dry pan.

The upper pan float guards begin at X978, only 3 mm outside the nominal maximum head-axis position X975, at Y600, Y660 and Y720. The modeled router body is above their Z910 upper extent. **The eventual torch body and cable sweep must be checked against these guards before claiming the full 800 mm nominal axis travel as usable plasma cutting width.** An inboard torch-mount offset may resolve the interface, but its geometry depends on the actual torch. No such offset or torch bolt pattern is assumed in this package.

The controls cabinet is a conservative 508 × 406.4 × 203.2 mm purchased envelope standing upright in the front bay (X371.8–778.2, Y251.8–455, Z165–673), door forward, on a bolt-on 1 × 1 tube cage under pan bearers 1 and 2. Transfer-drill the enclosure back-panel pattern onto the cage rails; pre-drill the stringers Ø5.5 so the #12 screws self-drill only the bearer walls. A clip-on 1.5 mm drip cap covers the top in the 6.2 mm gap below the bearers. Thermal layout, glands and the internal panel remain open. Routine service is through the front door with power isolated — no draining, no pan or bed removal.

Follow the independent module-hoist procedure and its sampled swept-volume check. Remove all four drawdowns to the tray and take up sling slack before the last bolt. The bed check does not model rigging and does not certify the separate handheld spindle transfer.

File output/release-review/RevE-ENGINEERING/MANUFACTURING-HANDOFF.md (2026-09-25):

# Rev F manufacturing handoff

This is an engineering package in millimetres. The current release status is recorded in `PACKAGE-STATUS.md`; the existence of a STEP or DXF file does not release an unresolved supplier interface.

## Design basis

The requested nominal travel is X 800 mm, dual Y 1000 mm and Z 100 mm. Travel is actuator stroke, not a promise that every point on the larger support bed is machinable. Soft limits, home positions, tool offsets and the practical cutting envelope must follow the completed motion definition.

The selected modules are KHMOS HMS40 (X ASIN B0C7GQTRRX, two Y ASIN B0C7GN24S1) and RATTMMOTOR ZBX80 (B09MVYGLNQ). Independent guide rails carry router cutting moments; the small HMS40 carriages transmit drive force through floating links. Kraken V1.1 supplies the four onboard motor channels. No external stepper-driver boxes are included.

The router deck is a ONE-PIECE hoisted module: a welded steel ladder (two 2 × 2 × .120 rails at 1290, four 2 × 1.5 × .120 flat crossmembers at 938.4, four 6 mm lift ears), two glued 12.7 mm MDF layers surfaced in place by the machine, and ten full-length 20100 strips. Five packs of the selected extrusion contain ten 1220 mm sticks; each takes ONE cut to 1197 mm, no drilling. The nominal butted deck is 1000 × 1197 mm; the width stack of ten 100 ± 0.2 strips is absorbed at the free edges. Strips fasten with fifty M5 × 25 button screws from below into DIN 562 square nuts in the bottom slots; the module clamps to the ledgers with four M8 × 70 drawdowns and locates on two Ø10 dowels.

The bare extrusion workplane is Z 940.8 mm. A nominal 19 mm spoilboard makes Z 959.8 mm. Plasma slats are at Z 850 mm. The 109.8 mm difference exceeds the Z module's 100 mm travel, so tool changes require distinct, defined head mounting positions. Do not try to cover both modes solely by changing a work coordinate.

## File use

| Files | Purpose | Before manufacture |
|---|---|---|
| `step/*.step` | Complete assembly states and placement | Check the state name, unresolved interfaces and collision report. |
| `parts/*.step` | Nominal individual solid parts | Match part number, revision, material and operations. Purchased envelopes are reference geometry. |
| `dxf/*.dxf` | Flat-part contours and labeled machining references | Use millimetres. Inspect the layer meanings; a tap or pocket reference is not a through-cut command. |
| `cutlist.csv` / `.json` | Quantities, material, stock and operation notes | Exclude purchased envelopes from fabrication. Read guarded-export status. |
| `tube-cut-plan.json` / `TUBE-CUT-PLAN.md` | Full-length 2 × 2 tube blank nesting | Use the stated saw kerf and end trim. Do not pre-cut stock in half without re-nesting. |
| `nesting/*.dxf` | Material/thickness-specific placement | Select through-cut layers only. Stock borders and part marks are non-cut references. |
| `nesting/sheet-nesting.json` | Part counts and layout checks | Small material groups may be ordered as cut blanks or flat bar instead of whole sheets. |

DXFs are nominal geometry. The fabricator must apply its own tool diameter or kerf compensation, pierce lead-ins, tabs, cut order, feeds, workholding and verified machine postprocessor. No generic G-code is supplied: a program posted for an unspecified machine is not a usable manufacturing release.

## Fabrication sequence

1. Resolve the supplier and interface fields in the current status register before buying mating parts or drilling interface plates. Confirm the actual selected revisions and options.
2. Cut structural blanks from the final cut list. Deburr and identify every part. Add internal weld nuts, compression sleeves and access features before closing tubes. Keep sand out until welding and leak checks are finished.
3. Fixture the frame from its rail datum surfaces. Tack, measure both diagonals and rail-plane twist, then weld in a balanced sequence. Recheck after cooling; an as-welded tube surface is not a precision guide datum.
4. Finish the specified rail caps, seats and adapter faces. Where the cut list says 6.000, 8.000 or 12.000 mm finished thickness, do not silently substitute 6.35, 7.9375 or 12.7 mm stock. Machine the specified finished dimension or revise all affected interfaces and recheck the CAD.
5. Assemble the pan and vented reservoir, preserving drain slope, cleanout access, separate overflow routes and a permanently open vent. Leak-test before paint and electrical installation. Fill only to the stated 115 L total inventory mark with the pan drained.
6. Assemble and align the guides, gantry and drive-only links. Install limit targets and hard stops from the completed motion drawing. Verify free movement over the entire stroke before connecting motor power.
7. Weld the module ladder and set it on the ledgers. Screw and glue the MDF layers to the crossmembers, then surface the MDF top in the machine. Hoist the module onto stands, fit the strips with their square nuts and underside screws, reinstall, and only then fit the optional spoilboards. Verify the sampled hoist route with the weighed finished module.
8. Finish and ballast only stationary frame members. Recheck leveling and geometry with operating water inventory and the intended bed installed.
9. Install the segregated electrical panel, shields and cable management from the completed terminal drawing. Perform the low-current controller procedure in `controls/COMMISSIONING.md` before cutting.

Weld sizes, fastener engagement, pocket depths and tapping operations come from the part notes and detailed drawings; this sequence does not replace them. Measurement during assembly is normal commissioning work, separate from unresolved design dimensions.

## Supplier evidence and inspection

- The HMS40 dimensioned drawing establishes the carriage's 30 × 30 mm M4 mounting pattern, 65.5 mm top height and stroke-dependent overall envelope. It does not establish the actual motor torque-speed curve or winding-current convention.
- The selected iMetrx rail drawing gives M5 × 6 block holes and a stated 40 mm rail-hole pitch. Its 1500 mm rail/end-offset arithmetic is inconsistent. Resolve the exact drilled rail pattern or use a fully defined adjustable mounting scheme; do not substitute another brand's hole pitch.
- The ZBX80 listing provides the broad envelope but does not fully dimension the output mounting pattern or assembled mounting height. Customer reviews and scaled photographs do not close these mating dimensions.
- The spindle kit is the selected 65 × 259 mm, 1.5 kW, ER11 kit. Its supplied clamp and VFD are already included in the purchase price. The earlier ER17 mention is not a verified option for this ASIN.

Receipt inspection and subsequent machine testing remain necessary even after the design is released. Supplier confirmation closes missing design data; physical inspection checks that the delivered parts match it.

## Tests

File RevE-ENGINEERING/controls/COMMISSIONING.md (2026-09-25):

# Physical acceptance — execute on the prototype, record the results

No physical tests in this document have been performed. The software build and static checks are complete. Keep the torch trigger and VFD run circuits disconnected until the logic, stop chain and motion tests pass. Use a meter/logic analyzer and an unloaded mechanism first.

1. **Identity and power.** Verify the silk-screen says Kraken V1.1, the MCU is STM32H723, and S1–S4 sense resistors match the V1.1 0.050-ohm documentation. Verify the separate board/DC and motor power arrangements from BTT's manual. Confirm actual DC polarity, fusing and protective earth. Remove DIAG endstop jumpers for the four physical switches. Keep S5–S8 unwired.
2. **Bootloader and image.** Back up the original firmware/configuration. Use BTT's documented 128 KiB bootloader update route for this board, with the supplied engineering BIN. Verify the image hash against `verification.json`. Do not write this application image at flash address zero or overwrite the bootloader. USB enumeration, a usable grblHAL greeting, the expected board name, and stable repeated resets must pass before proceeding.
3. **Read the controller.** Save `$I`, `$$`, `$PINS` and the Trinamic diagnostic report. Verify four motor channels, independent Y2, no SPI initialization fault, Rsense=50 mOhm, 16 microsteps, and 500 mA RMS commissioning current. Check the actual enable and chip-select lines. S5–S8 must remain disabled and deselected. Measure driver/motor current according to the driver and motor documentation; a DC supply current reading is not phase RMS current.
4. **Inputs and stop chain.** Check every switch independently in status/pin reports before motion. Verify X/Y1/Y2/Z switches cannot be confused. Open each NC circuit and disconnect each connector to verify the intended fault indication. Establish inversion/pull-up settings from the actual interface. Operate E-stop/breakaway with the USB host disconnected and verify tool permission is removed by hardware. Check reset, bootloader mode and board-power loss leave the isolated tool output off.
5. **Scale and direction.** Confirm the selected modules really have 10 mm/rev X/Y screws and 5 mm/rev Z screw, with 1.8-degree motors. The compiled assumptions are X/Y=320 steps/mm and Z=640 at 16 microsteps. If the mechanical lead differs, correct it before motion. Jog only 1 mm at first, verifying direction, displacement and both Y motors. Determine `$3` and the ganged-direction inversion from actual motor mounting. Never determine direction by homing a fully assembled gantry at speed.
6. **Dual-Y home.** Square the gantry mechanically first. Enable homing only after switch polarity/direction are verified. With tool power inhibited, home at low speed and trigger Y1 and Y2 separately; the corresponding motor must stop while the other finishes within the 2.5 mm configured difference limit. Trigger only one switch as a deliberate fault and confirm the homing mismatch alarm before excessive racking. Set squaring offset from measured diagonals. The 2.5 mm value is an initial protective limit, not proven structural tolerance.
7. **Travel and motion.** Test soft/hard limits at low energy, measure actual travel margins, then set them to the measured usable envelope. Increase velocity/acceleration only after no-stall and load tests. Compile defaults are just 600 mm/min X/Y, 300 mm/min Z, and 20/20/10 mm/s² acceleration; these are not plasma cutting speeds. Choose motor RMS current from verified motor data and temperature tests before any loaded cutting qualification.
8. **Router interface.** Set `$350=0`, cold-reset, and verify the report says PLASMA Off. With VFD run disconnected, meter the isolated 0–10 V converter at `M3 S12000` and `M3 S24000`: expected calibrated speed requests are 5 V and 10 V. `M5`, reset, E-stop, broken interface power and disconnected USB must be tested against the final interface's intended behavior. Confirm only the router can be selected by the keyed circuit. Connect the VFD interface only after its documented terminal functions match; test rotation/cooling at appropriate supported speed without a cutter installed.
9. **Simulated plasma signals.** Confirm `$PINS` maps PD12/PD13/PD14 to the intended logical aux ports. Set `$367=0`, `$368=1`, `$369=2` only if that mapping is verified. Set `$360=1` (one start attempt), `$674=2` (sync Z after THC), and `$350=2`, then cold-reset. Verify the controller reports PLASMA Up/down with no 'mode changed' or 'failed to initialize' warning. Keep torch trigger disconnected. Simulate Arc OK and UP/DOWN from the actual isolated interface. During a slow XY line, measure Z pulses and motion in the proper direction, timing after THC delay, velocity anti-dive during deceleration, and Z position after THC ends. Verify each of no Arc OK, lost Arc OK, both UP and DOWN, stuck input, input unplugged, E-stop and breakaway stops/holds as intended; do not presume software behavior from a compile.
10. **Cutter integration and cutting.** Only the exact cutter/THC combination with a documented isolated CNC interface can proceed to this step. Verify the manual's torch trigger and arc-sensing connection with the interface supplier. Do not infer HF compatibility from 'pilot arc' or an AG60-style torch. Commission without automatic retries; validate pierce height/delay, cut height, THC response and stop behavior on scrap at supported cutting speed. Run repeated starts while observing USB resets, input false triggers, lost steps and EMI. A failed test blocks live cutting until corrected.

## Operational mode change after acceptance

Stop the job, `M5`, inhibit tool power, move to the defined safe tool-change position, change the bed/head and hardware mode selector, select `$350=0` for router or `$350=2` for plasma, and cold-reset the motion controller. Read back the active mode and input health before restoring tool permission. Re-home if machine position or power was lost; re-probe the selected bed/workpiece. No firmware reflash is required for ordinary mode swaps.

The two control settings profiles are intentionally not auto-sent: limit polarity, homing direction and aux-port mapping depend on the physical harness and must first be measured. A CB1/SBC may be a USB G-code host; this motion image runs on Kraken itself and does not run Klipper.

## Recorded results

| Check | Current result |
|---|---|
| Compiler/linker, router and plasma environments | PASS |
| Compiler/linker, single hybrid image | PASS |
| Official pin/connector comparison and collision checks | PASS in `verification.json` |
| Bootloader vector and flash region check | PASS in `verification.json` |
| Physical boot, SPI, currents, motion and homing | NOT PERFORMED |
| Isolated interfaces and independent E-stop circuit | NOT PERFORMED |
| Real-time THC, cutter compatibility, EMI and cutting | NOT PERFORMED |

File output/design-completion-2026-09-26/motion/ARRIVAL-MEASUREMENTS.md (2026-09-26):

# Small measurement record that finishes the purchased interfaces

Use millimeters. Record the measuring tool and its stated uncertainty. Do not
force a guessed screw into a purchased hole. A photo records the datum/part
identity; it is not used to scale a dimension.

## Y pair - when the already-ordered modules arrive

| Record | Y left | Y right |
| --- | --- | --- |
| Full package/module/motor label; 1000 travel and10 lead identity | pending | pending |
| Base width/height, motor projection and cable outlet | pending | pending |
| Base slot centerline(s) from an identified outer edge | pending | pending |
| Supplied nut: thread/pitch, width/thickness, usable screw engagement and insertion route | pending | pending |
| Nonmotor end datum to output center at both usable travel limits; distinguish hard stop from usable limit | pending | pending |
| Output4-hole pattern/thread/depth and output-face height (compare published65.5 height,30 x30 M4 pattern) | pending | pending |

Also record if one full screw revolution moves the output10 mm while unloaded.
Match the two modules before drilling either chassis mount. Keep the output
carriages installed on their guides. The independent HGR guides carry the
gantry moment; the HMS40 modules provide drive thrust through the floating links.

## Z - obtain drawing before order, or measure the purchased100 mm unit

| Datum / interface | Required entry |
| --- | --- |
| Output height H | Distance from actual base mounting face to output mounting face; not just carriage-body thickness |
| Output fixing holes1-4 | For each: X/Y from the same two carriage edges, thread and pitch or plain bore, usable depth, backside access, ownership as accessory fixing hole |
| Base nut interface | Slot centerline, nut geometry/thread, usable engagement, insertion route and flat seating area |
| Motor flange | Mount hole coordinates/diameters, pilot diameter/depth, shaft diameter/projection and coupling type/bore/clamp engagement |
| Stroke datum | Output location at both usable ends, available overtravel, end-block and switch clearances |

The larger guide-assembly bores are not assumed to be accessory fixing holes.
Record the original motor label and keep the coupling undisturbed until the
replacement plan is dimensionally established.

## Existing torch - no model purchase required to take these measurements

1. Diameter of the straight insulated barrel at the actual clamping zone, at
   both ends and in two directions; permitted straight clamp length.
2. Distance along the axis from the nozzle tip to the lower end of that zone,
   plus the largest head diameter below it.
3. Body/lead projection above the clamp and the manufacturer's minimum lead
   bend radius, or the exact lead part number for obtaining it.
4. Torch and source label/connector identity. VIV ARC CUT-50 and AG60-style shape
   do not determine starting method, machine connection or isolated voltage tap.

These measurements define the physical mount. They do not authorize an
unverified torch-start or raw arc-voltage electrical connection.

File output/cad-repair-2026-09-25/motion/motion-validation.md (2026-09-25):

# Motion subsystem verification

**Result: PASS** for the sampled nominal configurations below.

Original two rail-cap blanks after frame_details.make_frame sets their assembled datum, before make_motion drills holes. Other frame parts and spacers are excluded from this subsystem screen.

| Gantry Y | Head X | Z lift | Valid solids | Unresolved intersections | Documented overlaps |
| ---: | ---: | ---: | ---: | ---: | ---: |
| 1275 | 575 | 100 | 293 | 0 | 52 |
| 275 | 175 | 0 | 293 | 0 | 52 |
| 275 | 975 | 100 | 293 | 0 | 52 |
| 1275 | 175 | 100 | 293 | 0 | 52 |
| 1275 | 975 | 0 | 293 | 0 | 52 |

Local/world volume mismatches: 0.

Five configurations of the motion subsystem only. No claim of continuous swept-volume clearance or complete machine strength/commissioning.

The original unraised fixture was 6 mm too low and produced 22 spurious clashes per state. The test now obtains the cap datum from the assembly frame builder. Supplier interfaces, operational tool/cable geometry and Z retention remain unresolved; a passing screen does not release those items.

Exact source hashes, cap bounds and configurations are recorded in `motion-validation.json`.

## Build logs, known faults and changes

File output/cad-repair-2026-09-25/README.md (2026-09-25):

# Rev G repairs and remaining work — 25 September 2026

**The previous model was incomplete and inaccurate. Rev G changes the geometry; it does not declare the machine finished.** Current exports are in [RevG-CAD](../release-review/RevG-CAD/README.md). The historical 29-finding audit is preserved unchanged.

## Corrected design

- Six 500 x397 mm panels replace the hoisted module. Ten 1220 mm bars supply thirty 397 mm pieces; 29 mm/bar remains for kerfs and trim.
- Four 924 mm beams, actual bearing seats, compression sleeves and round/relieved locators connect the bed to the chassis. Front seats unbolt after beam1 rests independently on beam2, opening the lowering portal.
- Six separate spoilboards are modeled after the 1 mm skim. Their faces lie inside nominal X175..975/Y121.4..1121.4 center travel; actual cutter and guard clearance is still required.
- All 24 loose top-slot nuts leave the extrusion before panel rotation and are stored threaded onto their removed screws. No imaginary nut retention.
- Actual stringer holes, a welded sloped drip shield, guard floor clearance and adapter recess orientation replace incorrect geometry. Unsupported carriage bolts and defective legacy torch clamps are omitted.

## Verification and limits

Both exported configurations contain 1283 valid solids, with zero unresolved static overlaps above the checker threshold; STEP readback checks solid counts and total volume. There are 201 individual STEP parts and 103 flat DXFs. Purchased or guarded interfaces are excluded from production-part exports.

- [Full-machine router poses](motion/revg-full-machine-poses.json): nine discrete positions; no continuous cutting or dual-Y-skew claim.
- [Panel handling](motion/revg-panel-path.json): 36 conservative continuous segments, in order 6→1, with already stored panels retained as obstacles.
- [Spoilboard handling](spoil-transfer-check.json): 60 continuous segments, in order 4, 3, 2, 1, 6, 5; nuts remain installed until boards are off.
- [Beam handling](beam-path-check.json): 25 continuous segments in order 1, 2, 3, 4, including temporary resting on beam2.
- [Nut evacuation](nut-evacuation-check.json): 24 nuts, each sliding to the open profile end and lifting through the joint. Travel to the tray and pickup/finger access are excluded.
- [Targeted motion and export corrections](motion/README.md); [frame repair evidence](frame/README.md).

These are nominal geometry checks. Zero overlap allows intentional contact and does not provide a fabrication-tolerance margin. Large-part paths exclude hands, small fasteners, front-seat/tool transfers, cables, joint capacity and positive storage/temporary-restraint qualification. The spindle/torch interfaces and whole-machine stiffness remain incomplete.

## Conversion is manual

The proposed sequence removes 52 screws/clamp fasteners plus 24 loose nuts, as well as the panels, boards, beams, two front seats and router tool. It is not automatic or advertised as quick-change. Manual handling remains an explicit working assumption pending owner preference. The [detailed sequence](bed-architecture.md) includes nominal masses, actual waypoints and limitations. Reinstall the bed to empty the racks before cabinet service.

## Status of every original finding

“Geometry corrected” addresses the cited CAD defect only. “Partial” and “open” are not closed engineering requirements. No total closure count is used to suggest manufacturing readiness.

| Finding | Current status | Change or remaining requirement |
|---|---|---|
| BED01 | PARTIAL | Six panels, separate boards and four beams now store inside the frame. Prescribed large-part paths are checked continuously. Manual preference, small-part transfers, human access and positive retention remain open. |
| BED02 | OLD DEFECT REMOVED | Unsupported MDF sub-bed and its five broken-edge seats are absent. New 20 mm ties carry 15 mm washers with nominal full bearing; slot/preload qualification remains BED04. |
| BED03 | PARTIAL | No unreachable full sub-bed surfacing is specified. Six spoilboard faces lie inside nominal center travel. Final cutter/guard clearance, seat map and repeat-installation accuracy remain unqualified. |
| BED04 | OPEN | Actual T-slot lips and M5 nuts still carry preload. No unsupported torque, uplift or creep rating is issued. |
| BED05 | PARTIAL | Gap-bridging weldnuts replaced by bearing plates, attached bosses and real compression sleeves. Weld strength, local tube-wall loads and tightening method still need qualification. |
| BED06 | PARTIAL | Round/relieved locator geometry is defined. Front seats are removable with clearance bolts; no automatic return-to-zero is claimed. Map seats and re-probe; qualify repeatability and fits. |
| BED07 | PARTIAL | 10 x 5.5 mm tie slots provide +/-2.25 mm nominal lateral M5-shank movement. Actual accumulated profile tolerances must fit that allowance. |
| BED08 | GEOMETRY CORRECTED | Finished spoilboards are 18 mm, explicitly skimmed 1 mm from rough 19 mm stock. The STEP now represents that finished stack. |
| BED09 | OPEN | Legacy strength screen is not used as whole-machine evidence. Tool, gantry, frame, seats, joints and feet require a combined load/deflection analysis. |
| BED10 | OLD JOINT REMOVED | MDF-to-steel TEK restraint is absent from the new bed. Independent cabinet TEK fasteners are a separate detail; new panel/beam joints still need qualification. |
| BED11 | PARTIAL | No assumed owner winch, sling or external parking. Manual components have nominal masses and routes. Handling preference, reach and restraint remain unqualified. |
| BED12 | PARTIAL | New continuous geometric checks cover ordered panel, board and beam paths with previously stored parts. They exclude fingers, tolerance stack, small-part transfers and retention; nine router poses are still discrete samples. |
| BED13 | PARTIAL | Nominal panel mass ~3.866 kg and beam mass ~5.060 kg use modeled solids and stated densities. Weigh finished assemblies; real hardware, welds and residue are not validated by those estimates. |
| BED14 | OPEN | Frame, feet, pan and reservoir support/load stability have no released structural rating. |
| MT01 | GEOMETRY CORRECTED | Both adapter front recesses have matching vertical STEP/DXF orientation; reconstructed void comparison passes. The physical purchased mating interface remains guarded. |
| MT02 | GUARDED, NOT COMPLETED | Invalid legacy torch-clamp solids are excluded from Rev G and guarded in source. A real measured torch clamp still needs design. |
| MT03 | OPEN | No installed, dimensioned plasma torch, floating head or breakaway. The second assembly is named BED_STORED and is not an operational plasma setup. |
| MT04 | CHECK FIXED | Motion fixture uses the actual raised rail-cap datum; the earlier22 clashes were fixture errors. Targeted and full-machine pose results are reported separately. |
| MT05 | OPEN / CLAIM CORRECTED | Supplier70 mm spacing applies to smaller5 mm holes; thread, longitudinal pitch and output height are unconfirmed. Removed guessedM6 screws; adapter production export is guarded. |
| MT06 | OPEN | HMS/HGR/Z mounting, actual motor/driver requirements and power-loss Z retention are unresolved. |
| MT07 | OPEN | Operational cutters, torch geometry, cable/lead bends, workholding and independent dual-Y skew still need integrated checks. |
| FW-01 | OPEN | Selected valve, pump, fittings and complete hoses/service route are not fully modeled. The CAD pan/tank does not imply an operational automatic water system. |
| FW-02 | GEOMETRY CORRECTED | Cabinet stringers now contain the specified6 mm bores through both walls; unsupported screw/stringer collision allowances removed. |
| FW-03 | GEOMETRY CORRECTED | Undefined folded cap replaced by actual sloped roof, separate welded lip, four cage tabs and M5 fasteners. Sampled shield service path checked against the frame subset; actual cabinet door still unknown. |
| FW-04 | OPEN | A fully demonstrated reservoir lid removal route past the rear brace is still absent. Trays on the lid must be emptied for service. |
| FW-05 | GEOMETRY CORRECTED | Drained-level guard moved upward. Minimum nominal clearance including slot play is 10.3713 mm, with 8 mm as-built requirement. Wet calibration remains open. |
| FW-06 | OPEN | Right pan guards remain close to maximum nominal tool center. Actual cutting tool/torch and useful plasma area need verification. |
| FW-07 | OPEN | Full frame stiffness, fastening, foot reactions, leveling and overturning are not qualified. |
| FW-08 | OPEN | Stored parts occupy the cabinet access zone: reinstall the bed to empty racks before cabinet service. Actual enclosure door, thermal layout, glands and hose separation remain open. |

## Reproduction

Use CadQuery 2.7/OpenCascade, ezdxf 1.4.4 and Python 3.12 for the CAD scripts. Run `build_revg.py` from the shared source directory; it writes the separate RevG-CAD package. The checks in this folder and `verify_revg_motion.py` / `verify_revg_panel_path.py` reproduce the evidence. Run `render_revg.py` after exports, then the repository-root `build_concept_revg.py` for the PDF review copy. Sources and readback hashes are recorded with the outputs.

The current square-tube schedule nests 30 modeled 2 x 2 x 0.120 inch blanks into five full 20-foot bars with 3 mm kerf / 10 mm trim. This excludes other tube sizes and is a cutting schedule, not a material quote. General sheet nesting is a layout envelope, not a recommendation to buy whole sheets for small parts. The owner’s 12 x 12 aluminum stock quantity/alloy is unverified. Twenty-four 250 x 20 ties cannot all come from one 12 x 12 piece.

No new total delivered price, final CAM post, firmware release, supplier message or purchase is implied. The [supplier request](SUPPLIER-DRAWING-REQUEST.md) is an unsent draft.

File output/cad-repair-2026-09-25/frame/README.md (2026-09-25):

# Frame detail corrections — 25 September 2026

These changes repair FW02 geometry, FW03 manufactured shield definition and FW05 nominal clearance from the historical CAD audit. They do not release the complete machine for fabrication.

## Cabinet stringers — FW02

Both `CAB_STRINGER` instances now contain two actual Ø6.0 mm bores through both tube walls. The local axes are X12.7 / Y12.6 and X12.7 / Y486.8, along Z. The nominal Ø5.5 mm screw shank has 0.25 mm radial clearance. Hole coordinates and the drilling operation appear in the part notes, which feed `part-operations.json` when the package is regenerated.

The stringer/screw collision exceptions were removed. The distinct self-drilling engagement into the bearer wall remains intentional. Both corrected individual stringer STEP samples were read back and checked; their removed volume equals four wall penetrations by a Ø6.0 mm drill. Screw-to-stringer overlap is zero.

## Drip shield — FW03

The former flat sheet with unspecified hems is replaced by an actual two-piece welded shield: a 436.4 × 233.211660 × 1.5 mm roof and a 436.4 × 20 × 1.5 mm front lip. Both are plain mild steel, continuously sealed at their joint and coated after welding. Both local flats match their STEP shapes. There are no bends and no assumed K factor or bend allowance.

The roof mounts rear high at a 1% slope, with front underside datum (356.8, 236.8, 675.5) mm. Four separate 3.048 mm tabs weld to the cage stringers; four modeled M5x20 screws and M5 nyloc nuts retain the shield through real Ø5.5 mm holes. No enclosure holes or load-bearing roof features are assumed. Roof-to-tab contact is verified. The roof and front lip fuse into a valid single-solid weldment.

The rear edge intentionally has no downturned lip, so it cannot catch the enclosure during withdrawal. After removing all four M5 bolts/nuts, translate the shield 230 mm forward parallel to its slope and lower it 100 mm into the front bay for hand removal. The route was sampled at 10 mm stations against the modeled frame, water equipment and nominal enclosure reserve, with no clashes. The reserve is not an actual door/hinge/latch model.

The installed shield clears the nominal enclosure by **2.6499 mm**. After welding and coating, verify at least 2 mm actual roof-to-enclosure clearance and 1 mm actual bearer clearance through the withdrawal route; rework the shield/tabs if those gauges fail. The selected enclosure drawing, fabrication distortion and physical service check remain release holds.

## Drained-level guard — FW05

The PAN_EMPTY carrier mount moved from Z802 to Z812; its guard underside moved from Z740 to Z750. Its dedicated backrail limits nominal carrier adjustment to Z812–832. The lowest possible setting including slot/shank radial play is Z811.7.

The rebuilt guard has **10.6713 mm** minimum distance to the actual sloped pan floor. At the lowest slot-play position it has **10.3713 mm**, leaving **2.3713 mm** for combined fabrication/datum variation while preserving the specified **8 mm minimum as-built clean gap**. Verify the whole guard footprint with a gauge after welding; rework a bracket that fails that gap. The carrier remains removable for brushing and washout.

This moves the float and therefore changes its relationship to water level. **The supplier's actual reed trip offset and the 60-second post-trip drain performance remain wet-commissioning holds.** Do not lower or extend the slots to recover an assumed trip point, and do not treat this float as proof of a bone-dry pan.

## Verification and limits

`verify_frame_repairs.py` freshly builds 443 frame/water/control components. All are valid single solids; the subset has zero unresolved positive-volume intersections. The constrained PAN_EMPTY carrier was also checked at both physical slot-play limits and 2 mm stations through the range. These sampled geometry checks are not a full machine motion or structural qualification.

`verification.json` contains source hashes, exact measurements, drilling metadata, collision results and generated STEP readback results. The STEP/DXF files in this evidence folder are verification samples; the main package still needs regeneration by the integration build.

FW03 manufactured geometry is now defined; its fit to the actual selected enclosure remains part of FW08 integration. FW01 plumbing, FW04 reservoir service, FW07 full-frame qualification and FW08 vendor enclosure integration remain open.

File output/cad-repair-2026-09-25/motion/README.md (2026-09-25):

# Motion export repairs — 25 September 2026

MT01 and MT04 are repaired in the generators. MT05's misleading dimensions and fastening instructions are corrected, but the physical Z-carriage connection remains unresolved.

- **MT01:** non-through DXF slots now retain their angle. Both adapter recesses are vertical, 30×11 mm and 6.6 mm deep. The check reconstructed each exported DXF contour and compared its extruded void to the imported STEP pocket: symmetric volume difference below 1e-9 mm³. STEP readback is valid; DXF units are millimetres and its audit passes.
- **MT04:** the motion test now obtains the actual rail-cap datum from `frame_details.make_frame`, before drilling motion holes. The earlier targeted motion-and-caps check covered five configurations of 293 valid solids each, with zero unresolved intersections and zero local/world volume mismatches. This is a separate subsystem check; its count is two lower than the corrected audit fixture because the unsupported M6 carriage screws were removed.
- **MT05:** the exact supplier drawing assigns 70 mm transverse spacing to the smaller Ø5 fixing holes. No confirmed thread, longitudinal pitch or output mounting-face height was found. The adapter is guarded from individual production exports and the two unsupported M6 carriage screws are absent. See [Z-interface evidence](z-interface-resolution.md).

[Adapter evidence](adapter-export-check.json), [motion results](motion-validation.json) and [generated motion summary](motion-validation.md) record the results and source hashes. `check_adapter_export.py` reproduces the targeted adapter check. The motion test supports `--output-dir` so validation evidence can be regenerated without replacing historical records.

`TOOL_ADAPTER_110.PROVISIONAL.step`, its DXF and operations JSON are explicit comparison artifacts. They do not release the supplier mating interface for manufacture. Export an integrated revision to a clean output directory: the current exporter skips guarded parts but does not remove stale individual files from previous exports.

## Integrated Rev G verification

The corrected working CAD is exported separately in [RevG-CAD](../../release-review/RevG-CAD). Its [engineering manifest](../../release-review/RevG-CAD/engineering-manifest.json) records **1283 valid solids and zero unresolved intersections in both ROUTER and BED_STORED configurations**, with successful STEP round trips. Historical Rev E/F outputs and the historical audit are retained separately. BED_STORED is a storage layout, not an operational plasma assembly.

The final [full-machine motion evidence](revg-full-machine-poses.json) passes **nine complete router poses**: all eight X/Y/Z travel-box corners plus center. Every pose contains 1283 valid world and local solids, zero unresolved intersections and zero local/world volume mismatches. The run used the actual frame-raised cap datum and completed with unchanged source hashes. These remain sampled static axis positions; continuous axis motion, cutters, workpieces, hoses/cables and independent-Y skew are not proved.

The final [ordered panel-path evidence](revg-panel-path.json) proves **36 path segments for six panels**, stored in order 6→1. The complete straight translations use swept AABB bounds against actual fixed solids. Rotations use 2-degree cells with radius-based bounds covering all intermediate angles, rather than relying only on sampled poses. All bounds were clear above the 1e-6 mm³ Boolean volume tolerance and remained inside the original machine footprint; the smallest conservative footprint margin was 7.665 mm. Every final panel placement matches its CAD storage datum, and source hashes remained unchanged throughout the run.

Panel-path preconditions are explicit: router spindle/clamps already stored; six spoilboards, 24 screws, 24 top-slot nuts and 16 panel-clamp sets already removed and stored; four support beams, their bolts and the removable front seats/bolts still installed. Already stored panels remain in the fixed geometry for each later move. This panel check **does not prove those prerequisite transfers, beam or front-seat handling, human hand clearance, physical tolerance clearance or safe manual handling**. No mounting strength, Z retention or unresolved purchased interface is released by these checks.

`verify_revg_motion.py` and `verify_revg_panel_path.py` in the engineering source folder reproduce these final checks. Files with `preliminary` or `before-pinchbolt-storage-fix` in their names retain superseded verification runs and are not the final evidence.

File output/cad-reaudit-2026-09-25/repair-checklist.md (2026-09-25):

# CAD repair checklist

All findings are open. The audit did not modify the design. Complete the architecture and datum work before freezing dependent details.

Audit records: 29; high priority: 14; medium priority: 15.

- [ ] **BED01 / P1 — The exchange route violates the within-footprint requirement**
  Select a mechanically defined in-footprint exchange/storage architecture, or record an explicit user-approved requirement change before treating this as the chosen design. Include support, retention and storage in CAD. See [Bed and structure](bed-structure.md).

- [ ] **BED02 / P1 — Five deck clamping stations break the MDF support edge**
  Relocate the five stations to supported bottom-slot centers or redesign the support width; recheck the full washer and pocket footprint against edges, notches and crossmembers, then regenerate both MDF layers and drawings. See [Bed and structure](bed-structure.md).

- [ ] **BED03 / P1 — The required full-face surfacing operation is outside the tool envelope**
  Define a feasible machined datum process with fixture and cutter access, change the support/motion placement, or specify external machining from measured final datums. Do not claim weld and ledger errors disappear until the operation is achievable and reinstallation repeatability is checked. See [Bed and structure](bed-structure.md).

- [ ] **BED04 / P1 — The selected M5 joint still loads the extrusion lips under tightening**
  Qualify the actual extrusion/nut/washer/MDF joint for assembly preload, local uplift, shear and creep; issue a controlled fastening method and replacement/reinspection limits. Do not automatically reinstate the prior0.35 N m number without validation. See [Bed and structure](bed-structure.md).

- [ ] **BED05 / P1 — Four drawdown weldnuts have an unclosed physical attachment detail**
  Detail the actual purchased weldnut, weld/bearing seat and assembly access. Use a compatible hole/seat or a designed bridge plate/boss; specify the weld and qualify local tube-wall load transfer at the chosen preload before releasing the ledger machining. See [Bed and structure](bed-structure.md).

- [ ] **BED06 / P1 — Locator fits and receiver engagement are not manufacturing-defined**
  Define a datum/fit scheme, typically one round locator plus a relieved locator or an equivalently justified alternative, with actual bushings if required. Specify machining after welding, positional/height tolerances, lead-in and retention, and measure repeated install flatness. See [Bed and structure](bed-structure.md).

- [ ] **BED11 / P1 — The sling and support system is outside the collision and load analysis**
  After resolving the footprint architecture, define a lifting-rated device, support/parking mechanism, actual rigging and credible unequal sharing; verify ear/weld/anchor loads and sweep the full rigging envelope. Weigh the finished module and include an operating stability/load case. See [Bed and structure](bed-structure.md).

- [ ] **FW-01 / P1 — Selected water hardware and its complete service route are missing from the CAD**
  Use verified selected valve/pump/strainer envelopes and connection datums; model supported gravity plumbing, hose bend envelopes, the anti-siphon discharge and removal spaces. Include an installation drawing with fitting/thread types and receipt-selected nipple lengths. Do not invent supplier dimensions. See [Frame, water and packaging](frame-water-packaging.md).

- [ ] **FW-07 / P1 — Whole-frame rigidity and support stability remain unverified**
  Set a required tool-to-work deflection budget and actual load cases, then check the assembled frame, connections, feet and support surface with appropriate analysis and/or a measured load test. Determine mass/center of gravity for router/plasma/service configurations and close anchoring/leveling requirements. Preserve the member-screen qualification. See [Frame, water and packaging](frame-water-packaging.md).

- [ ] **MT01 / P1 — Adapter front counter-slots are rotated 90 degrees in the delivered DXF**
  Carry the slot angle in non-through operation metadata, rotate operation geometry in write_dxf, regenerate adapter STEP/DXF/operations, and compare the recess orientations and depths explicitly. See [Motion and tools](motion-tools.md).

- [ ] **MT02 / P1 — Exported torch-clamp halves do not contain their claimed fastening features**
  Define the actual owned torch barrel/insulated clamping zone from measurement or its exact drawing, design and model both clamp halves and every fastening operation, prove the installed orientation, and guard the incomplete parts until that is done. See [Motion and tools](motion-tools.md).

- [ ] **MT03 / P1 — Plasma setup CAD has no installed plasma cutting tool**
  Create the real plasma-tool assembly and a distinct installed plasma configuration with its measured nozzle datum, mount, floating/breakaway mechanism and cable envelope; then verify travel and state transitions. See [Motion and tools](motion-tools.md).

- [ ] **MT05 / P1 — Z output attachment is provisional and its slot/thread claims are not sufficient to choose hardware**
  Resolve a measured or supplier-approved mating drawing; specify the exact hole type, number of bolts, washers/nuts and engagement, and revise the slot claim and provisional adapter. Preserve the hold until the joint has a defined load path. See [Motion and tools](motion-tools.md).

- [ ] **MT06 / P1 — HMS/HGR/Z mounting and power-off Z retention are still unresolved**
  Close exact supplier/measured interfaces, select the Z retention arrangement and its attachments, add its envelope and release criteria, and complete Z limits/homing before freezing the CAD. See [Motion and tools](motion-tools.md).

- [ ] **BED07 / P2 — Nominal strip-width tolerance is not absorbed solely at free edges**
  Inspect the actual profile and nut, calculate the cumulative lateral fit, and define independent strip datums, compensated hole locations or designed transverse clearance without weakening bearing seats. Carry the supplier tolerance and water-guard clearance through the check. See [Bed and structure](bed-structure.md).

- [ ] **BED08 / P2 — The modeled final stack omits the instructed1 mm skim**
  Separate rough and final thicknesses, define the finished support plane and remaining reface limit, and propagate those dimensions to screw lengths, nut engagement, work offsets and clearance checks. See [Bed and structure](bed-structure.md).

- [ ] **BED09 / P2 — The stiffness screen is not an upper bound on full machine compliance**
  Retain the member arithmetic as a limited screening result, remove unsupported bond/bound claims, establish acceptable bed-to-tool deflection, and verify the complete structural loop under representative loads and humidity/reinstallation cycles. See [Bed and structure](bed-structure.md).

- [ ] **BED10 / P2 — TEK restraint and pull-through are not qualified for the actual assembly**
  Select the exact screw and characterize its joint in the actual tube/MDF stack for pullout, head pull-through and assembly stripping, including representative local clamp loads. Correct the pitch arithmetic and retain a realistic load path. See [Bed and structure](bed-structure.md).

- [ ] **BED12 / P2 — Sampled positive-volume checks do not certify tolerance or continuous clearance**
  Define and check a swept-volume or justified adaptive clearance analysis for all retained hardware and attachments, include uncertainty margins and the actual footprint, and then verify physical clearances during commissioning. See [Bed and structure](bed-structure.md).

- [ ] **BED13 / P2 — Lifting mass has inconsistent estimation bases**
  Use one explicit mass basis, correct the washer density classification, include additions/uncertainty and compute center of gravity for the selected rigging. Replace the estimate with a weighed value before use. See [Bed and structure](bed-structure.md).

- [ ] **BED14 / P2 — Frame and pan support assumptions do not define a released structural rating**
  Define the actual mass/load envelope and performance targets; evaluate complete operating cases and load transfer through welds, feet, pan bearers and frame, then measure tool-to-bed deflection and repeatability. Keep the documented sand limitation. See [Bed and structure](bed-structure.md).

- [ ] **FW-02 / P2 — Cabinet stringers claim predrilled clearance holes but export as plain tubes**
  Cut the two through-clearance holes into each stringer solid and individual export, add their local dimensions to fabrication operations, and narrow/remove the exception once the clearance is real. Retain the separate intentional self-drilling penetration in the bearer wall. See [Frame, water and packaging](frame-water-packaging.md).

- [ ] **FW-03 / P2 — Drip-cap flat pattern does not define the instructed folded part**
  Choose the actual folded cap geometry and attachment, model the installed folded shape, then supply a developed flat with bend lines, radii, bend allowance and corner reliefs. Check door swing and lifting/removal using the selected enclosure. See [Frame, water and packaging](frame-water-packaging.md).

- [ ] **FW-04 / P2 — Reservoir lid removal has no demonstrated route past the rear brace**
  Define and collision-check a practical washout service sequence with lid-mounted equipment, cable/hose disconnects and handling clearance. If that needs pan removal, state it. Otherwise introduce a suitable service hatch or a structurally justified removable obstruction, then rerun the assembled route. See [Frame, water and packaging](frame-water-packaging.md).

- [ ] **FW-05 / P2 — Drained-level guard has only 0.672 mm clearance to the pan floor**
  Allocate a minimum as-built/debris clearance and adjust the guard or sensor arrangement accordingly. Preserve adequate adjustment travel and wet-calibrate the resulting drained threshold and delay. Check access for cleaning the narrow gap. See [Frame, water and packaging](frame-water-packaging.md).

- [ ] **FW-06 / P2 — Pan guards are outside center travel but very close to its right edge**
  Integrate the selected torch/nozzle/clamp and stock envelopes in plasma operating states. Define any reduced usable cut region or relocate guards outside the complete envelope; do not equate center travel with clear tool clearance. See [Frame, water and packaging](frame-water-packaging.md).

- [ ] **FW-08 / P2 — Cabinet access is plausible but an enclosure block does not prove service clearance**
  Use the selected enclosure drawing to model or conservatively bound the door/hinges/latch and removable panel; verify access, transfer holes, cable bend/entry spaces and thermal layout. Retain packaging-envelope release status until closed. See [Frame, water and packaging](frame-water-packaging.md).

- [ ] **MT04 / P2 — The 22 stored motion clashes come from an unraised cap fixture**
  Make the test share the assembled cap datum before hole generation and regenerate its report/prose from actual results. Do not waive the overlaps or translate already-drilled caps, which moves the holes to the wrong height. See [Motion and tools](motion-tools.md).

- [ ] **MT07 / P2 — Travel and service checks omit operational cutters, leads and dual-Y skew**
  Define actual cutting-tool and plasma-tip datums and permissible stickout/workholding, include leads/covers, then extend the full-machine checks to the completed operational assemblies, continuous/swept motion and a bounded dual-Y squaring/skew scenario. Keep the test scope visible. See [Motion and tools](motion-tools.md).

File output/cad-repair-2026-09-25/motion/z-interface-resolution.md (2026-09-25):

# ZBX80 interface evidence — 25 September 2026

**The three missing mating fields remain open. A mistaken hole identification is corrected.** No substitute model or photograph-scaled dimension was adopted.

The exact [100 mm ASIN B09MVYGLNQ listing](https://www.amazon.com/dp/B09MVYGLNQ) was accessible during this check. Its gallery still references the saved seller images in the existing source manifest. The relevant original images are:

- [Top drawing](https://m.media-amazon.com/images/I/61WxScULDML._SL1500_.jpg): 90 mm transverse by 50 mm along-travel carriage, smaller Ø5 holes and larger Ø7 bores. **The 70 mm transverse dimension connects the smaller Ø5 hole row.** It does not dimension the larger Ø7 bore pattern. The longitudinal spacing, thread and depth of the small holes are absent.
- [Fixing-hole identification](https://m.media-amazon.com/images/I/71E5oziXi9L._SL1500_.jpg): identifies four small output fixing holes. It does not specify their thread, depth or datum tolerance.
- [Side drawing](https://m.media-amazon.com/images/I/61HH-r4RqQL._SL1500_.jpg): dimensions the carriage body at 35 mm high, base extrusion at20 mm, end blocks at67/78 mm. **It does not dimension the assembled base-mounting-plane to output-face distance.** Adding20+35 omits the intervening guide/block stack.
- [Bottom drawing](https://m.media-amazon.com/images/I/51wBxuUiRML._SL1500_.jpg): supplies profile annotations and identifies movable M5 nuts, without a complete nut/undercut/interface drawing.

The current listing text also identifies M5 nuts for the side and bottom slots. Those nuts are separate from the output fixing holes; the label does not establish the output-hole thread.

## CAD action

The incorrect assertion that the Ø7 bores have70 mm transverse spacing is removed from `motion_details.py`. The two unsupported M6×16 carriage screw solids and their overlap permissions are removed. A trueØ7 plain bore cannot provide an M6 internal thread, and an M6 shank cannot pass a trueØ5 hole. The model now explicitly identifies the missing fastening connection.

The two7×30 adapter slots and their11×30 recesses remain provisional visualization geometry. They are **not** a verified fit to the four supplier fixing holes. The individual adapter export is guarded until the mating drawing is established. MT01 closes only the internal STEP/DXF rotation/depth mismatch; MT05 remains an open physical interface.

## Exact information needed to finish this connection

| Field | Required evidence / measurement |
| --- | --- |
| Base-to-output height | With the module resting on its actual base mounting face, measure perpendicular distance to the flat output mounting face. Record the datum faces, actual value and measurement uncertainty. Do not substitute the35 mm carriage-body height. |
| Four output fixing holes | For every small fixing hole: transverse and along-travel coordinates from specified carriage edges, plain or threaded, bore diameter or thread major diameter and pitch, usable thread/through depth, entry counterbore if any and backside access. Confirm that the four holes are available for the added tool, not occupied guide fasteners. |
| Attachment stack | After the above: select screw count, grade, head/washer, length, usable engagement or nut arrangement and installation access; assess the connection load path. Rebuild the adapter around that verified pattern. |
| Base attachment | Nut type/thread, undercut width/depth, slot centerlines, available insertion route and usable screw engagement. |
| Operating datums | Output location at both stroke limits, allowable overtravel, motor/cable projection and the separate power-off Z restraint. |

## Research boundary

The existing field register, saved top/side/fixing-hole drawings and exact-ASIN current listing were checked. Targeted public searches did not produce a revision-controlled primary drawing closing the missing height, longitudinal output-hole pitch or hole thread/depth. Generic ZBX80/Plus variants and third-party CAD were not substituted for this exact module. No supplier message was sent.

The earlier field register's appended25 September paragraph also misattributes70 mm toØ7 and claims the slots accommodate an unknown pitch. That paragraph is superseded by this evidence; preserve the original record as history. The related torch-barrel assumption is not verified by these Z-slide sources and remains unresolved.

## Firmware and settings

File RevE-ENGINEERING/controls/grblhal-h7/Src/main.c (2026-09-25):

/*

  main.c - driver code for STM32H7xx ARM processors

  Part of grblHAL

  Copyright (c) 2021-2024 Terje Io
  Copyright (c) 2022-2024 Jon Escombe
  Some parts (C) COPYRIGHT STMicroelectronics - code created by IDE

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
  You should have received a copy of the GNU General Public License
  along with grblHAL. If not, see <http://www.gnu.org/licenses/>.
*/

#include "main.h"
#include "driver.h"

#include "grbl/grbllib.h"

void SystemClock_Config(void);
void MPU_Config(void);

int main(void)
{

    /* Configure the MPU attributes as Device memory for ETH DMA descriptors */
    MPU_Config();

#if L1_CACHE_ENABLE
    /* Enable I-Cache */
    SCB_EnableICache();

    /* Enable D-Cache */
    SCB_EnableDCache();
#endif

    HAL_Init();
    SystemClock_Config();

    if(!(CoreDebug->DEMCR & CoreDebug_DEMCR_TRCENA_Msk)) {
        CoreDebug->DEMCR |= CoreDebug_DEMCR_TRCENA_Msk;
        DWT->LAR = 0xC5ACCE55;
        DWT->CYCCNT = 0;
        DWT->CTRL |= DWT_CTRL_CYCCNTENA_Msk;
        DWT->LAR = 0;
    }

    grbl_enter();
}

void MPU_Config(void)
{
  MPU_Region_InitTypeDef MPU_InitStruct;

  /* Disable the MPU */
  HAL_MPU_Disable();

  /* Configure the MPU as Strongly ordered for not defined regions */
  MPU_InitStruct.Enable = MPU_REGION_ENABLE;
  MPU_InitStruct.BaseAddress = 0x00;
  MPU_InitStruct.Size = MPU_REGION_SIZE_4GB;
  MPU_InitStruct.AccessPermission = MPU_REGION_NO_ACCESS;
  MPU_InitStruct.IsBufferable = MPU_ACCESS_NOT_BUFFERABLE;
  MPU_InitStruct.IsCacheable = MPU_ACCESS_NOT_CACHEABLE;
  MPU_InitStruct.IsShareable = MPU_ACCESS_SHAREABLE;
  MPU_InitStruct.Number = MPU_REGION_NUMBER0;
  MPU_InitStruct.TypeExtField = MPU_TEX_LEVEL0;
  MPU_InitStruct.SubRegionDisable = 0x87;
  MPU_InitStruct.DisableExec = MPU_INSTRUCTION_ACCESS_DISABLE;

  HAL_MPU_ConfigRegion(&MPU_InitStruct);

  /* Configure the MPU attributes as Device not cacheable
     for ETH DMA descriptors */
  MPU_InitStruct.Enable = MPU_REGION_ENABLE;
  MPU_InitStruct.BaseAddress = 0x2400C000;
  MPU_InitStruct.Size = MPU_REGION_SIZE_1KB;
  MPU_InitStruct.AccessPermission = MPU_REGION_FULL_ACCESS;
  MPU_InitStruct.IsBufferable = MPU_ACCESS_BUFFERABLE;
  MPU_InitStruct.IsCacheable = MPU_ACCESS_NOT_CACHEABLE;
  MPU_InitStruct.IsShareable = MPU_ACCESS_NOT_SHAREABLE;
  MPU_InitStruct.Number = MPU_REGION_NUMBER1;
  MPU_InitStruct.TypeExtField = MPU_TEX_LEVEL0;
  MPU_InitStruct.SubRegionDisable = 0x00;
  MPU_InitStruct.DisableExec = MPU_INSTRUCTION_ACCESS_ENABLE;

  HAL_MPU_ConfigRegion(&MPU_InitStruct);

  /* Configure the MPU attributes as Normal Write through
     for LwIP Rx pool */
  MPU_InitStruct.Enable = MPU_REGION_ENABLE;
  MPU_InitStruct.BaseAddress = 0x24008000;
  MPU_InitStruct.Size = MPU_REGION_SIZE_16KB;
  MPU_InitStruct.AccessPermission = MPU_REGION_FULL_ACCESS;
  MPU_InitStruct.IsBufferable = MPU_ACCESS_NOT_BUFFERABLE;
  MPU_InitStruct.IsCacheable = MPU_ACCESS_CACHEABLE;
  MPU_InitStruct.IsShareable = MPU_ACCESS_SHAREABLE;
  MPU_InitStruct.Number = MPU_REGION_NUMBER2;
  MPU_InitStruct.TypeExtField = MPU_TEX_LEVEL0;
  MPU_InitStruct.SubRegionDisable = 0x00;
  MPU_InitStruct.DisableExec = MPU_INSTRUCTION_ACCESS_ENABLE;

  HAL_MPU_ConfigRegion(&MPU_InitStruct);

  /* Configure the MPU attributes as Normal Non Cacheable
     for LwIP RAM heap which contains the Tx buffers */
  MPU_InitStruct.Enable = MPU_REGION_ENABLE;
  MPU_InitStruct.BaseAddress = 0x24000000;
  MPU_InitStruct.Size = MPU_REGION_SIZE_32KB;
  MPU_InitStruct.AccessPermission = MPU_REGION_FULL_ACCESS;
  MPU_InitStruct.IsBufferable = MPU_ACCESS_NOT_BUFFERABLE;
  MPU_InitStruct.IsCacheable = MPU_ACCESS_NOT_CACHEABLE;
  MPU_InitStruct.IsShareable = MPU_ACCESS_SHAREABLE;
  MPU_InitStruct.Number = MPU_REGION_NUMBER3;
  MPU_InitStruct.TypeExtField = MPU_TEX_LEVEL1;
  MPU_InitStruct.SubRegionDisable = 0x00;
  MPU_InitStruct.DisableExec = MPU_INSTRUCTION_ACCESS_ENABLE;

  HAL_MPU_ConfigRegion(&MPU_InitStruct);

  /* Configure the MPU QSPI flash */
  MPU_InitStruct.Enable = MPU_REGION_ENABLE;
  MPU_InitStruct.BaseAddress = 0x90000000;
  MPU_InitStruct.Size = MPU_REGION_SIZE_128MB;
  MPU_InitStruct.AccessPermission = MPU_REGION_FULL_ACCESS;
  MPU_InitStruct.IsBufferable = MPU_ACCESS_BUFFERABLE;
  MPU_InitStruct.IsCacheable = MPU_ACCESS_CACHEABLE;
  MPU_InitStruct.IsShareable = MPU_ACCESS_SHAREABLE;
  MPU_InitStruct.Number = MPU_REGION_NUMBER4;
  MPU_InitStruct.TypeExtField = MPU_TEX_LEVEL1;
  MPU_InitStruct.SubRegionDisable = 0x0;
  MPU_InitStruct.DisableExec = MPU_INSTRUCTION_ACCESS_DISABLE;

  HAL_MPU_ConfigRegion(&MPU_InitStruct);

  /* Enable the MPU */
  HAL_MPU_Enable(MPU_PRIVILEGED_DEFAULT);
}

void SystemClock_Config(void)
{
    // Clock configuration
    //
    // - 480MHZ system clock
    // - 48MHz clock from PLL1Q - USB, SDMMC1, SPI1/SPI2/SPI3, QUADSPI/OCTOSPI
    // - 48MHz clock from PLL2Q - SPI4/SPI5
    // - 12MHz clock from PLL2R - optional SDMMC1 clock source with NUCLEO_SLOW_SDMMC_CLOCK
    //
    // WeAct MiniSTM32H7xx & BTT SKR3 using 25MHz crystal
    // Nucleo dev board using 8MHz clock source (STLink MCO)

    RCC_OscInitTypeDef RCC_OscInitStruct = {0};
    RCC_ClkInitTypeDef RCC_ClkInitStruct = {0};
    RCC_PeriphCLKInitTypeDef PeriphClkInitStruct = {0};

    /** Supply configuration update enable
    */
    HAL_PWREx_ConfigSupply(PWR_LDO_SUPPLY);
    /** Configure the main internal regulator output voltage
    */
    __HAL_PWR_VOLTAGESCALING_CONFIG(PWR_REGULATOR_VOLTAGE_SCALE0);

    while(!__HAL_PWR_GET_FLAG(PWR_FLAG_VOSRDY)) {}

#if RTC_ENABLE
    /** Configure LSE Drive Capability */
    HAL_PWR_EnableBkUpAccess();
    __HAL_RCC_LSEDRIVE_CONFIG(RCC_LSEDRIVE_LOW);
#endif

#if defined(STM32H743xx)

#if defined(NUCLEO_H743) // Nucleo H743 dev board with 8MHz clock source
#define FLASH_LATENCY FLASH_LATENCY_4

#if RTC_ENABLE
    RCC_OscInitStruct.OscillatorType = RCC_OSCILLATORTYPE_HSE|RCC_OSCILLATORTYPE_LSE;
    RCC_OscInitStruct.LSEState = RCC_LSE_ON;
#else
    RCC_OscInitStruct.OscillatorType = RCC_OSCILLATORTYPE_HSE;
#endif
    RCC_OscInitStruct.HSEState = RCC_HSE_ON;
    RCC_OscInitStruct.PLL.PLLState = RCC_PLL_ON;
    RCC_OscInitStruct.PLL.PLLSource = RCC_PLLSOURCE_HSE;
    RCC_OscInitStruct.PLL.PLLM = 2;
    RCC_OscInitStruct.PLL.PLLN = 240;
    RCC_OscInitStruct.PLL.PLLP = 2;
    RCC_OscInitStruct.PLL.PLLQ = 20;
    RCC_OscInitStruct.PLL.PLLR = 2;
    RCC_OscInitStruct.PLL.PLLRGE = RCC_PLL1VCIRANGE_2;
    RCC_OscInitStruct.PLL.PLLVCOSEL = RCC_PLL1VCOWIDE;
    RCC_OscInitStruct.PLL.PLLFRACN = 0;

    PeriphClkInitStruct.PLL2.PLL2M = 2;
    PeriphClkInitStruct.PLL2.PLL2N = 240;
    PeriphClkInitStruct.PLL2.PLL2P = 2;
    PeriphClkInitStruct.PLL2.PLL2Q = 20;
    PeriphClkInitStruct.PLL2.PLL2R = 80;
    PeriphClkInitStruct.PLL2.PLL2RGE = RCC_PLL1VCIRANGE_2;
    PeriphClkInitStruct.PLL2.PLL2VCOSEL = RCC_PLL1VCOWIDE;
    PeriphClkInitStruct.PLL2.PLL2FRACN = 0;

#else // Common configuration for all other H743 boards with 25MHz crystals
#define FLASH_LATENCY FLASH_LATENCY_4

#if RTC_ENABLE
    RCC_OscInitStruct.OscillatorType = RCC_OSCILLATORTYPE_HSE|RCC_OSCILLATORTYPE_LSE;
    RCC_OscInitStruct.LSEState = RCC_LSE_ON;
#else
    RCC_OscInitStruct.OscillatorType = RCC_OSCILLATORTYPE_HSE;
#endif
    RCC_OscInitStruct.HSEState = RCC_HSE_ON;
    RCC_OscInitStruct.PLL.PLLState = RCC_PLL_ON;
    RCC_OscInitStruct.PLL.PLLSource = RCC_PLLSOURCE_HSE;
    RCC_OscInitStruct.PLL.PLLM = 5;
    RCC_OscInitStruct.PLL.PLLN = 192;
    RCC_OscInitStruct.PLL.PLLP = 2;
    RCC_OscInitStruct.PLL.PLLQ = 20;
    RCC_OscInitStruct.PLL.PLLR = 2;
    RCC_OscInitStruct.PLL.PLLRGE = RCC_PLL1VCIRANGE_2;
    RCC_OscInitStruct.PLL.PLLVCOSEL = RCC_PLL1VCOWIDE;
    RCC_OscInitStruct.PLL.PLLFRACN = 0;

    PeriphClkInitStruct.PLL2.PLL2M = 5;
    PeriphClkInitStruct.PLL2.PLL2N = 192;
    PeriphClkInitStruct.PLL2.PLL2P = 2;
    PeriphClkInitStruct.PLL2.PLL2Q = 20;
    PeriphClkInitStruct.PLL2.PLL2R = 80;
    PeriphClkInitStruct.PLL2.PLL2RGE = RCC_PLL2VCIRANGE_2;
    PeriphClkInitStruct.PLL2.PLL2VCOSEL = RCC_PLL2VCOWIDE;
    PeriphClkInitStruct.PLL2.PLL2FRACN = 0;

#endif // H743 other boards

#elif defined (STM32H723xx)

#if defined(NUCLEO_H723) //  // Nucleo H723 dev board with 8MHz clock source
#define FLASH_LATENCY FLASH_LATENCY_3

#if RTC_ENABLE
    RCC_OscInitStruct.OscillatorType = RCC_OSCILLATORTYPE_HSE|RCC_OSCILLATORTYPE_LSE;
    RCC_OscInitStruct.LSEState = RCC_LSE_ON;
#else
    RCC_OscInitStruct.OscillatorType = RCC_OSCILLATORTYPE_HSE;
#endif
    RCC_OscInitStruct.HSEState = RCC_HSE_ON;
    RCC_OscInitStruct.PLL.PLLState = RCC_PLL_ON;
    RCC_OscInitStruct.PLL.PLLSource = RCC_PLLSOURCE_HSE;
    RCC_OscInitStruct.PLL.PLLM = 2;
    RCC_OscInitStruct.PLL.PLLN = 120;
    RCC_OscInitStruct.PLL.PLLP = 1;
    RCC_OscInitStruct.PLL.PLLQ = 10;
    RCC_OscInitStruct.PLL.PLLR = 1;
    RCC_OscInitStruct.PLL.PLLRGE = RCC_PLL1VCIRANGE_2;
    RCC_OscInitStruct.PLL.PLLVCOSEL = RCC_PLL1VCOWIDE;
    RCC_OscInitStruct.PLL.PLLFRACN = 0;

    PeriphClkInitStruct.PLL2.PLL2M = 2;
    PeriphClkInitStruct.PLL2.PLL2N = 120;
    PeriphClkInitStruct.PLL2.PLL2P = 1;
    PeriphClkInitStruct.PLL2.PLL2Q = 10;
    PeriphClkInitStruct.PLL2.PLL2R = 40;
    PeriphClkInitStruct.PLL2.PLL2RGE = RCC_PLL1VCIRANGE_2;
    PeriphClkInitStruct.PLL2.PLL2VCOSEL = RCC_PLL1VCOWIDE;
    PeriphClkInitStruct.PLL2.PLL2FRACN = 0;

#else  // Common configuration for all other H723 boards with 25MHz crystals
#define FLASH_LATENCY FLASH_LATENCY_3

#if RTC_ENABLE
    RCC_OscInitStruct.OscillatorType = RCC_OSCILLATORTYPE_HSE|RCC_OSCILLATORTYPE_LSE;
    RCC_OscInitStruct.LSEState = RCC_LSE_ON;
#else
    RCC_OscInitStruct.OscillatorType = RCC_OSCILLATORTYPE_HSE;
#endif
    RCC_OscInitStruct.HSEState = RCC_HSE_ON;
    RCC_OscInitStruct.PLL.PLLState = RCC_PLL_ON;
    RCC_OscInitStruct.PLL.PLLSource = RCC_PLLSOURCE_HSE;
    RCC_OscInitStruct.PLL.PLLM = 5;
    RCC_OscInitStruct.PLL.PLLN = 96;
    RCC_OscInitStruct.PLL.PLLP = 1;
    RCC_OscInitStruct.PLL.PLLQ = 10;
    RCC_OscInitStruct.PLL.PLLR = 2;
    RCC_OscInitStruct.PLL.PLLRGE = RCC_PLL1VCIRANGE_2;
    RCC_OscInitStruct.PLL.PLLVCOSEL = RCC_PLL1VCOWIDE;
    RCC_OscInitStruct.PLL.PLLFRACN = 0;

    PeriphClkInitStruct.PLL2.PLL2M = 5;
    PeriphClkInitStruct.PLL2.PLL2N = 96;
    PeriphClkInitStruct.PLL2.PLL2P = 1;
    PeriphClkInitStruct.PLL2.PLL2Q = 10;
    PeriphClkInitStruct.PLL2.PLL2R = 40;
    PeriphClkInitStruct.PLL2.PLL2RGE = RCC_PLL1VCIRANGE_2;
    PeriphClkInitStruct.PLL2.PLL2VCOSEL = RCC_PLL1VCOWIDE;
    PeriphClkInitStruct.PLL2.PLL2FRACN = 0;

#endif // STM32H723xx other boards
#endif // STM32H723xx

    /** Initializes the RCC Oscillators according to the specified parameters
    * in the RCC_OscInitTypeDef structure.
    */
    if (HAL_RCC_OscConfig(&RCC_OscInitStruct) != HAL_OK)
    {
      Error_Handler();
    }

    /** Initializes the CPU, AHB and APB buses clocks
    */
    RCC_ClkInitStruct.ClockType = RCC_CLOCKTYPE_HCLK|RCC_CLOCKTYPE_SYSCLK
                                |RCC_CLOCKTYPE_PCLK1|RCC_CLOCKTYPE_PCLK2
                                |RCC_CLOCKTYPE_D3PCLK1|RCC_CLOCKTYPE_D1PCLK1;
    RCC_ClkInitStruct.SYSCLKSource = RCC_SYSCLKSOURCE_PLLCLK;
    RCC_ClkInitStruct.SYSCLKDivider = RCC_SYSCLK_DIV1;
    RCC_ClkInitStruct.AHBCLKDivider = RCC_HCLK_DIV2;
    RCC_ClkInitStruct.APB3CLKDivider = RCC_APB3_DIV2;
    RCC_ClkInitStruct.APB1CLKDivider = RCC_APB1_DIV2;
    RCC_ClkInitStruct.APB2CLKDivider = RCC_APB2_DIV2;
    RCC_ClkInitStruct.APB4CLKDivider = RCC_APB4_DIV2;

    if (HAL_RCC_ClockConfig(&RCC_ClkInitStruct, FLASH_LATENCY) != HAL_OK)
    {
      Error_Handler();
    }

    PeriphClkInitStruct.PeriphClockSelection  = RCC_PERIPHCLK_SPI123 | RCC_PERIPHCLK_SPI45 | RCC_PERIPHCLK_I2C123 |
                                                RCC_PERIPHCLK_USART16 | RCC_PERIPHCLK_USART234578;
    PeriphClkInitStruct.Spi123ClockSelection  = RCC_SPI123CLKSOURCE_PLL;
    PeriphClkInitStruct.Spi45ClockSelection   = RCC_SPI45CLKSOURCE_PLL2;
    PeriphClkInitStruct.I2c1235ClockSelection = RCC_I2C123CLKSOURCE_D2PCLK1;
    PeriphClkInitStruct.Usart16ClockSelection = RCC_USART16CLKSOURCE_PCLK2;
    PeriphClkInitStruct.Usart234578ClockSelection = RCC_USART234578CLKSOURCE_PCLK1;

#if RTC_ENABLE
    PeriphClkInitStruct.PeriphClockSelection = PeriphClkInitStruct.PeriphClockSelection | RCC_PERIPHCLK_RTC;
    PeriphClkInitStruct.RTCClockSelection = RCC_RTCCLKSOURCE_LSE;
#endif

#if SPIFLASH_ENABLE
#if defined(STM32H743xx)
    PeriphClkInitStruct.PeriphClockSelection = PeriphClkInitStruct.PeriphClockSelection | RCC_PERIPHCLK_QSPI;
    PeriphClkInitStruct.QspiClockSelection = RCC_QSPICLKSOURCE_PLL;
#elif defined(STM32H723xx)
    PeriphClkInitStruct.PeriphClockSelection = PeriphClkInitStruct.PeriphClockSelection | RCC_PERIPHCLK_OSPI;
    PeriphClkInitStruct.OspiClockSelection = RCC_OSPICLKSOURCE_PLL;

#endif
#endif //SPIFLASH_ENABLE

#ifdef CAN_PORT
    PeriphClkInitStruct.PeriphClockSelection = PeriphClkInitStruct.PeriphClockSelection | RCC_PERIPHCLK_FDCAN;
    PeriphClkInitStruct.FdcanClockSelection = RCC_FDCANCLKSOURCE_PLL;
#endif //CAN_PORT

#if SDCARD_ENABLE
    PeriphClkInitStruct.PeriphClockSelection = PeriphClkInitStruct.PeriphClockSelection | RCC_PERIPHCLK_SDMMC;
#ifdef NUCLEO_SLOW_SDMMC_CLOCK
    PeriphClkInitStruct.SdmmcClockSelection = RCC_SDMMCCLKSOURCE_PLL2;
#else
    PeriphClkInitStruct.SdmmcClockSelection = RCC_SDMMCCLKSOURCE_PLL;
#endif //NUCLEO_SLOW_SDMMC_CLOCK
#endif //SDCARD_ENABLE

    if (HAL_RCCEx_PeriphCLKConfig(&PeriphClkInitStruct) != HAL_OK)
    {
      Error_Handler();
    }
}

/**
  * @brief  This function is executed in case of error occurrence.
  * @retval None
  */
void Error_Handler(void)
{
  /* User can add his own implementation to report the HAL error return state */
  __disable_irq();
  while (1);
}

#ifdef USE_FULL_ASSERT
/**
  * @brief  Reports the name of the source file and the source line number
  *         where the assert_param error has occurred.
  * @param  file: pointer to the source file name
  * @param  line: assert_param error line source number
  * @retval None
  */

#include <stdio.h>
#include "grbl/hal.h"

void assert_failed(uint8_t *file, uint32_t line)
{
    char buf[100];

    if(hal.stream.write) {
        sprintf(buf, "Wrong parameters value: file %s on line %lu\r\n", file, line);
        hal.stream.write(buf);
    }
}
#endif

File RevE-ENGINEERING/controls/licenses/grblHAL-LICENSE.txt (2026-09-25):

------------------------------------------------------------------------------
COPYRIGHT NOTICE FOR grblHAL STM32F3xx driver:
------------------------------------------------------------------------------

grblHAL - Embedded CNC g-code interpreter and motion-controller

Copyright (c) 2019-2021 Terje Io

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
------------------------------------------------------------------------------
COPYRIGHT NOTICE(S) FOR WORK CONTAINED IN THIS SOFTWARE:
------------------------------------------------------------------------------

/*
 * GNU General Public License:
 *  Copyright (c) 2011-2016 Sungeun K. Jeon for Gnea Research LLC
 *  Copyright (c) 2009-2011 Simen Svale Skogsrud
*/

/*******************************************************************************
  * COPYRIGHT(c) 2017 STMicroelectronics
  *
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
  ******************************************************************************
  */

/**
  ******************************************************************************
  * @file    STM32 USB driver files
  * @author  MCD Application Team
  * @brief   ...
  ******************************************************************************
  * @attention
  *
  * <h2><center>&copy; Copyright (c) 2015 STMicroelectronics.
  * All rights reserved.</center></h2>
  *
  * This software component is licensed by ST under Ultimate Liberty license
  * SLA0044, the "License"; You may not use this file except in compliance with
  * the License. You may obtain a copy of the License at:
  *                      www.st.com/SLA0044
  *
  ******************************************************************************
  */

/*
 * Copyright (c) 2009-2018 Arm Limited. All rights reserved.
 *
 * SPDX-License-Identifier: Apache-2.0
 *
 * Licensed under the Apache License, Version 2.0 (the License); you may
 * not use this file except in compliance with the License.
 * You may obtain a copy of the License at
 *
 * www.apache.org/licenses/LICENSE-2.0
 *
 * Unless required by applicable law or agreed to in writing, software
 * distributed under the License is distributed on an AS IS BASIS, WITHOUT
 * WARRANTIES OR CONDITIONS OF ANY KIND, either express or implied.
 * See the License for the specific language governing permissions and
 * limitations under the License.
 */
 
/*----------------------------------------------------------------------------/
/  FatFs - Generic FAT Filesystem Module  R0.13c                              /
/-----------------------------------------------------------------------------/
/
/ Copyright (C) 2018, ChaN, all right reserved.
/
/ FatFs module is an open source software. Redistribution and use of FatFs in
/ source and binary forms, with or without modification, are permitted provided
/ that the following condition is met:
/
/ 1. Redistributions of source code must retain the above copyright notice,
/    this condition and the following disclaimer.
/
/ This software is provided by the copyright holder and contributors "AS IS"
/ and any warranties related to this software are DISCLAIMED.
/ The copyright owner or contributors be NOT LIABLE for any damages caused
/ by use of this software.
/
/----------------------------------------------------------------------------*/

------------------------------------------------------------------------------
GNU GPLv3 TERMS AND CONDITIONS REPRODUCED HERE FOR CLARITY:
------------------------------------------------------------------------------

                    GNU GENERAL PUBLIC LICENSE
                       Version 3, 29 June 2007

 Copyright (C) 2007 Free Software Foundation, Inc. <http://fsf.org/>
 Everyone is permitted to copy and distribute verbatim copies
 of this license document, but changing it is not allowed.

                            Preamble

  The GNU General Public License is a free, copyleft license for
software and other kinds of works.

  The licenses for most software and other practical works are designed
to take away your freedom to share and change the works.  By contrast,
the GNU General Public License is intended to guarantee your freedom to
share and change all versions of a program--to make sure it remains free
software for all its users.  We, the Free Software Foundation, use the
GNU General Public License for most of our software; it applies also to
any other work released this way by its authors.  You can apply it to
your programs, too.

  When we speak of free software, we are referring to freedom, not
price.  Our General Public Licenses are designed to make sure that you
have the freedom to distribute copies of free software (and charge for
them if you wish), that you receive source code or can get it if you
want it, that you can change the software or use pieces of it in new
free programs, and that you know you can do these things.
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

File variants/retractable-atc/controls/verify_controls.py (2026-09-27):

"""Run offline behavioral, GPIO, decoder and electrical arithmetic checks."""
from pathlib import Path
from dataclasses import replace,asdict
from copy import deepcopy
from itertools import product
import hashlib,json,re,sys
from interlock import Dock,Config,Inputs,Command,State
from input_adapter import PLAN,decode_gpio,config_valid,INIT_WRITES

HERE=Path(__file__).resolve().parent
ROOT=HERE.parents[2]
checks=[]
def check(name,condition,detail=None):
    checks.append({'name':name,'passed':bool(condition),'detail':detail})

class Rig:
    """Independent idealized plant: saturating physical motion, limit cams and
    spring pins; no machine IO. This does not test force, braking or bounce."""
    def __init__(self):
        self.dock=Dock(Config(qualified_fixture=True))
        self.now=0
        self.sequence=0
        self.slide=0.0
        self.door=0.0
        self.park_pin=True
        self.deploy_pin=True
        self.catch=True
        self.kit=False
        self.running=False
        self.pose_epoch=1
        self.snapshots={}
        self.trace=[]
        self.out=None
    def __deepcopy__(self,memo):
        new=object.__new__(Rig)
        memo[id(self)]=new
        new.__dict__={k:({} if k=='snapshots' else deepcopy(v,memo)) for k,v in self.__dict__.items()}
        return new
    def tick(self,cmd=Command(),mutate=None,dt=20):
        if self.out:
            # These assertions are independent physical permission requirements,
            # evaluated BEFORE changing pins in response to this cycle's output.
            if self.out.slide_velocity:
                assert not self.park_pin and not self.deploy_pin,'slide driven against pin'
                assert self.door>=163.0 and self.catch,'slide driven with unretained door'
            if self.out.shutter_velocity:
                assert self.slide<=1 and self.park_pin and not self.catch,'door moved unsafely'
            self.slide=max(0,min(200,self.slide+self.out.slide_velocity*dt/1000))
            self.door=max(0,min(164,self.door+self.out.shutter_velocity*dt/1000))
            self.park_pin=not self.out.unlock
            self.deploy_pin=not self.out.unlock
            self.catch=not self.out.shutter_catch_release
            if self.out.kit_cover_action=='OPEN':self.kit=True
            elif self.out.kit_cover_action=='CLOSE':self.kit=False
        self.now+=dt;self.sequence+=1
        x=Inputs(self.sequence,self.now,parked=self.slide<=.001,deployed=self.slide>=199.999,
                 park_pin_extended=self.park_pin,park_pin_retracted=not self.park_pin,
                 deploy_pin_extended=self.deploy_pin,deploy_pin_retracted=not self.deploy_pin,
                 shutter_open=self.door>=163.999,shutter_closed=self.door<=.001,
                 shutter_catch_extended=self.catch,shutter_catch_retracted=not self.catch,
                 kit_cover_open=self.kit,kit_cover_closed=not self.kit,
                 spindle_stopped=not self.running,spindle_running=self.running,
                 spindle_feedback_ms=self.now,axis_clear_ms=self.now,
                 toolpath_lease=True,toolpath_session=self.dock.session,
                 pose_epoch=self.pose_epoch,axis_clear_epoch=self.pose_epoch,
                 slide_mm=self.slide,shutter_position_mm=self.door)
        if mutate:x=replace(x,**mutate)
        self.out=self.dock.step(self.now,x,cmd)
        if not self.trace or self.trace[-1]['state']!=self.out.state.value:
            self.trace.append({'ms':self.now,'state':self.out.state.value,'slide_mm':self.slide,'shutter_mm':self.door})
        self.snapshots.setdefault(self.out.state,deepcopy(self))
        return self.out
    def wait_for(self,state,max_ms=40000):
        for _ in range(max_ms//20):
            if self.out and self.out.state==state:return
            o=self.tick()
            if o.state==State.FAULT:raise AssertionError(o.fault)
        raise AssertionError('never reached '+state.value)
    def boot(self):
        for _ in range(20):self.tick()
        self.tick(Command(acknowledge=True))
        assert self.out.state==State.PARKED
        self.tick()
    def deploy(self):
        self.boot();self.tick(Command(start_change=True));self.wait_for(State.READY)
    def tool(self):
        self.deploy();self.tick(Command(begin_tool=True));self.tick()
        self.running=True
        for _ in range(5):self.tick(Command(spindle_request=True))
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

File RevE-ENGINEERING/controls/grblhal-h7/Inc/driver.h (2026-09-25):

/*

  driver.h - driver code for STM32H7xx ARM processors

  Part of grblHAL

  Copyright (c) 2021-2026 Terje Io

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
  You should have received a copy of the GNU General Public License
  along with grblHAL. If not, see <http://www.gnu.org/licenses/>.
*/

//
// NOTE: do NOT change configuration here - edit my_machine.h instead!
//

#ifndef __DRIVER_H__
#define __DRIVER_H__

#include <stdbool.h>
#include <stdint.h>

#ifndef OVERRIDE_MY_MACHINE
#include "my_machine.h"
#endif

#include "main.h"
#include "pwm.h"

#if defined(MCP3221_ENABLE)
#define I2C_ENABLE 1
#define MCP3221_ENABLE_NEW MCP3221_ENABLE
#endif

#define OPTS_POSTPROCESSING

#include "grbl/driver_opts.h"

#include "timers.h"

#define DIGITAL_OUT(port, bit, on) { (port)->BSRR = (on) ? (bit) : ((bit) << 16); }
#define DIGITAL_IN(port, bit) (!!((port)->IDR & (bit)))

#define timer(t) timerN(t)
#define timerN(t) TIM ## t
#define timerBase(t) timerbase(t)
#define timerbase(t) TIM ## t ## _BASE
#define timerINT(t) timerint(t)
#define timerint(t) TIM ## t ## _IRQn
#define timerHANDLER(t) timerhandler(t)
#define timerhandler(t) TIM ## t ## _IRQHandler
#define timerCLKEN(t) timerclken(t)
#define timerclken(t) __HAL_RCC_TIM ## t ## _CLK_ENABLE
#define timerCCEN(c, n) timerccen(c, n)
#define timerccen(c, n) TIM_CCER_CC ## c ## n ## E
#define timerCCMR(p, c) timerccmr(p, c)
#define timerccmr(p, c) TIM ## p->CCMR ## c
#define timerOCM(p, c) timerocm(p, c)
#define timerocm(p, c) TIM_CCMR ## p ##_OC ## c ## M_1|TIM_CCMR ## p ##_OC ## c ## M_2
#define timerOCMC(p, c) timerocmc(p, c)
#define timerocmc(p, c) (TIM_CCMR ## p ##_OC ## c ## M|TIM_CCMR ## p ##_CC ## c ## S)
#define timerCCR(t, c) timerccr(t, c)
#define timerccr(t, c) TIM ## t->CCR ## c
#define timerCCP(c, n) timerccp(c, n)
#define timerccp(c, n) TIM_CCER_CC ## c ## n ## P
#define timerCR2OIS(c, n) timercr2ois(c, n)
#define timercr2ois(c, n) TIM_CR2_OIS ## c ## n
#define timerAF(t, f) timeraf(t, f)
#define timeraf(t, f) GPIO_AF ## f ## _TIM ## t
#define timerAPB2(t) (t == 1 || t == 8 || t == 15 || t == 16 || t == 17)

#define usart(t) usartN(t)
#define usartN(t) USART ## t
#define usartINT(t) usartint(t)
#define usartint(t) USART ## t ## _IRQn
#define usartHANDLER(t) usarthandler(t)
#define usarthandler(t) USART ## t ## _IRQHandler
#define usartCLKEN(t) usartclken(t)
#define usartclken(t) __HAL_RCC_USART ## t ## _CLK_ENABLE

#define TIMER_CLOCK_MUL(d) (d == RCC_HCLK_DIV1 ? 1 : (d == RCC_HCLK_DIV2 ? 2 : (d == RCC_HCLK_DIV4 ? 4 : 8)))

// Define GPIO output mode options

#define GPIO_SHIFT0   0
#define GPIO_SHIFT1   1
#define GPIO_SHIFT2   2
#define GPIO_SHIFT3   3
#define GPIO_SHIFT4   4
#define GPIO_SHIFT5   5
#define GPIO_SHIFT6   6
#define GPIO_SHIFT7   7
#define GPIO_SHIFT8   8
#define GPIO_SHIFT9   9
#define GPIO_SHIFT10 10
#define GPIO_SHIFT11 11
#define GPIO_SHIFT12 12
#define GPIO_SHIFT13 13
#define GPIO_MAP     14
#define GPIO_SINGLE  15

#ifndef IS_NUCLEO_DEVKIT
#if defined(NUCLEO_F756)
#define IS_NUCLEO_DEVKIT 1
#else
#define IS_NUCLEO_DEVKIT 0
#endif
#endif

#ifndef CONTROL_ENABLE
#define CONTROL_ENABLE (CONTROL_HALT|CONTROL_FEED_HOLD|CONTROL_CYCLE_START)
#endif

#if defined(BOARD_PROTONEER_3XX)
  #include "boards/protoneer_3.xx_map.h"
#elif defined(BOARD_GENERIC_UNO)
  #include "boards/uno_map.h"
#elif defined(BOARD_DRESCO_OCTAVE)
  #include "boards/dresco_octave_map.h"
#elif defined(BOARD_BTT_SKR_30)
  #include "boards/btt_skr_v3.0_map.h"
#elif defined(BOARD_BTT_OCTOPUS_MAX)
  #include "boards/btt_octopus_max_map.h"
#elif defined(BOARD_BTT_OCTOPUS_PRO)
  #include "boards/btt_octopus_pro_map.h"
#elif defined(BOARD_BTT_SCYLLA)
  #include "boards/btt_scylla_map.h"
#elif defined(BOARD_BTT_MANTA_M8P)
  #include "boards/btt_manta_m8p_v2_map.h"
#elif defined(BOARD_WEACT_MINI)
  #include "boards/weact_mini_map.h"
#elif defined(BOARD_REFERENCE)
  #include "boards/reference_map.h"
#elif defined(BOARD_MY_MACHINE)
  #include "boards/my_machine_map.h"
#else // default board
  #include "boards/generic_map.h"
#endif

#if DRIVER_SPINDLE_ENABLE && !defined(SPINDLE_ENABLE_PIN)
#warning "Selected spindle is not supported!"
#undef DRIVER_SPINDLE_ENABLE
#define DRIVER_SPINDLE_ENABLE 0
#endif

#if DRIVER_SPINDLE_DIR_ENABLE && !defined(SPINDLE_DIRECTION_PIN)
#warning "Selected spindle is not fully supported - no direction output!"
#undef DRIVER_SPINDLE_DIR_ENABLE
#define DRIVER_SPINDLE_DIR_ENABLE 0
#endif

#if DRIVER_SPINDLE_PWM_ENABLE && (!DRIVER_SPINDLE_ENABLE || !defined(SPINDLE_PWM_PIN))
#warning "Selected spindle is not supported!"
#undef DRIVER_SPINDLE_PWM_ENABLE
#define DRIVER_SPINDLE_PWM_ENABLE 0
#ifdef SPINDLE_PWM_PORT_BASE
#undef SPINDLE_PWM_PORT_BASE
#endif
#endif

// Define timer allocations.

#define STEPPER_TIMER_N             5
#define STEPPER_TIMER_BASE          timerBase(STEPPER_TIMER_N)
#define STEPPER_TIMER               timer(STEPPER_TIMER_N)
#define STEPPER_TIMER_CLKEN         timerCLKEN(STEPPER_TIMER_N)
#define STEPPER_TIMER_IRQn          timerINT(STEPPER_TIMER_N)
#define STEPPER_TIMER_IRQHandler    timerHANDLER(STEPPER_TIMER_N)

#if SPINDLE_ENCODER_ENABLE

#define RPM_COUNTER_N               3
#define RPM_COUNTER_BASE            timerBase(RPM_COUNTER_N)
#define RPM_COUNTER                 timer(RPM_COUNTER_N)
#define RPM_COUNTER_CLKEN           timerCLKEN(RPM_COUNTER_N)
#define RPM_COUNTER_IRQn            timerINT(RPM_COUNTER_N)
#define RPM_COUNTER_IRQHandler      timerHANDLER(RPM_COUNTER_N)

#define RPM_TIMER_N                 2
#define RPM_TIMER_BASE              timerBase(RPM_TIMER_N)
#define RPM_TIMER                   timer(RPM_TIMER_N)
#define RPM_TIMER_CLKEN             timerCLKEN(RPM_TIMER_N)
#define RPM_TIMER_IRQn              timerINT(RPM_TIMER_N)
#define RPM_TIMER_IRQHandler        timerHANDLER(RPM_TIMER_N)

#endif

#if TRINAMIC_UART_ENABLE
#ifndef TMC_UART_TIMER_N
#define TMC_UART_TIMER_N        7
#endif
#define TMC_UART_TIMER_BASE         timerBase(TMC_UART_TIMER_N)
#endif

#define IS_TIMER_BDTR(INSTANCE) (((INSTANCE) == TIM1) || \
                                 ((INSTANCE) == TIM8) || \
                                 ((INSTANCE) == TIM15) || \
                                 ((INSTANCE) == TIM16) || \
                                 ((INSTANCE) == TIM17))

#define IS_TIMER_CLAIMED(INSTANCE) (((INSTANCE) == STEPPER_TIMER_BASE) || \
                                    ((INSTANCE) == TMC_UART_TIMER_BASE))

// Adjust these values to get more accurate step pulse timings when required, e.g if using high step rates.
// The default values below are calibrated for 5 microsecond pulses on a H723 @ 480 MHz.
// NOTE: step output mode, number of axes and compiler optimization setting may all affect these values.
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

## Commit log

2026-09-25 Import private CNC plasma-router engineering project and audit status
    [BED_MDF_LOWER.dxf, BED_MDF_LOWER.step, BED_MDF_UPPER.dxf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]
2026-09-25 Record owner-reported VIV ARC CUT-50 and correct plasma interface gates
2026-09-25 Audit all CAD exports and document 29 design and fabrication findings
    [full-machine-poses.json]
2026-09-25 Repair Rev G bed geometry and publish verified CAD review
    [CAB_CAP_TAB_LEFT.dxf, CAB_CAP_TAB_LEFT.step, CAB_CAP_TAB_RIGHT.dxf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]
2026-09-26 Add Rev H bed restraints, water servicing and verified CAD
    [CAB_CAP_TAB_LEFT.dxf, CAB_CAP_TAB_LEFT.step, CAB_CAP_TAB_RIGHT.dxf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]
2026-09-26 Repair Rev I head, internal conversion, plumbing and control interfaces
    [CAB_CAP_TAB_LEFT.dxf, CAB_CAP_TAB_LEFT.step, CAB_CAP_TAB_RIGHT.dxf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]
2026-09-26 Add removable ATC dock and full-sheet development variants
    [ISO4762_M6x25.step, LOC_CARRIER_LAND_40_40_12.dxf, LOC_CARRIER_LAND_40_40_12.step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]
2026-09-26 Study 200 mm retractable ATC travel on both machine variants
    [change-allocation.step, deployed-allocation.step, parked-allocation.step]
2026-09-27 Develop retractable ATC mechanisms and interlock models for both machines
    [ADAPTER_STAND_L_0.dxf, ADAPTER_STAND_L_0.step, ADAPTER_STAND_L_1.dxf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]
2026-11-01 Add priced 4040 extrusion variant for woodworking and plasma
2026-11-01 Reengineer small 4080 table and publish scoped CAD audit
2026-11-01 Complete XR2 bed, reservoir service and retractable ATC engineering package
    Use the authorized 200 mm Z redesign for the full-bed ATC clearance case.
    Add mounted guards, supported reservoir cleaning/service, fabricated cassette
    joinery, retained slats and the removable ATC carrier with positive locks.
    Export and verify individual manufacturing solids and profiles, CAM surface
    references, combined stock nests and source-bound digital checks. Preserve
    supplier mating interfaces, physical acceptance and the unverified delivered
    budget as explicit release gates. Update the current design/PDF entry points.
2026-11-01 Record owned 300 mm-stroke Z pending fit assessment
2026-11-01 Integrate the owned ZBX80 300 mm candidate and repair the head joint
    Recover the already supplied RATTMMOTOR ZBX80 purchase evidence and retain
    the existing frame height with a nominal 300 mm physical stage. Assess the
    existing 200 mm working range without claiming full 300 mm qualification.
    Correct carrier/flange interference with a bearing-floor relief and complete
    the lower M6 holes with a deeper integral support. Add source-bound fit and
    repair checks, full proposal assemblies, read-back evidence and previews.
    Keep supplier fits, physical rigidity, retention and operating release open.
2026-11-02 Complete candidate motion/service evidence and disclose remaining owner integration
    Repair the front Y-stop bases and matched mounts, export the revised working-Z200 review assemblies, and bind the motion, service and manufacturing evidence to current source/output hashes.
    Recover the supplied original clamp/boot and later owner confirmations. Record the unresolved head, continuous HDPE/20100 bed, gantry and magazine-slide integration explicitly; exclude competing prov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
    Validation: scoped external/relative/static motion and in-footprint service proofs pass; both complete STEP assemblie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
2026-11-02 Integrate owner head and full HDPE/20100 bed on the 4080 table
    Preserve the owner clamp/boot solids on a removable billet dock. Add the full uncut bed, in-frame hinge bay, selected ATC slide and rear cover, motorized gravity drain, sectional guide storage and interlocked front-stop parking. Keep the owned 300mm Z and assess a 250mm working domain.
    Include three independently read-back STEP scenes, source-bound clearance/path checks, reconciled manufacturing references and exclusive stock allocations. Publish a visually checked review PDF and current status.
    The selected new bed/Basic-ATC goods already exceed the USD1000 cap before the frame and delivery. Exact supplier interfaces, work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
2026-11-05 Integrate actual ATC housing and repair head and bed load paths
    Use the original manufacturer magazine housing and mounting/pocket axes, passive endpoint captures, deeper billet arms and a corrected removable cover. Add an owned-stock rib and dowels to the router head. Detail all eight retained bed pins and bridge the crossmember bores with 80 washers and screws finished from75 to72mm.
    Rebuild all three STEP assemblies and previews, 329 manufacturing references, the820-row engineering takeoff and273 procurement families. Record14 actual AliExpress cart variants at117.26USD with tax/destination confirmation and the remaining cart scope explicit. Exclude owned equipment and reconcile14 exclus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
2026-11-05 Reconcile final bed handling figures and bind the current reach screen
2026-11-06 Optimize upright 4080 bed and fitted gantry joints
    Stand the four existing bed crossmembers on their strong axis, use one full
    HDPE layer, reconcile the metal preload columns and retained hardware, and
    preserve the wood/ATC workplane with the lowered wet/plasma interfaces.
    Replace the two guide strips with a continuous fitted steel rail face and
    end closures, using explicitly nested new hanger offcuts. Align rear arm
    access notches with the revised bed anchors after a real initial-tilt clash.
    Rebuild three assemblies, current custom STEP/DXF references, scoped geometry
    and transition proofs, the master/procurement schedules, price register and
    partial Amazon/AliExpress carts. Preserve physi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

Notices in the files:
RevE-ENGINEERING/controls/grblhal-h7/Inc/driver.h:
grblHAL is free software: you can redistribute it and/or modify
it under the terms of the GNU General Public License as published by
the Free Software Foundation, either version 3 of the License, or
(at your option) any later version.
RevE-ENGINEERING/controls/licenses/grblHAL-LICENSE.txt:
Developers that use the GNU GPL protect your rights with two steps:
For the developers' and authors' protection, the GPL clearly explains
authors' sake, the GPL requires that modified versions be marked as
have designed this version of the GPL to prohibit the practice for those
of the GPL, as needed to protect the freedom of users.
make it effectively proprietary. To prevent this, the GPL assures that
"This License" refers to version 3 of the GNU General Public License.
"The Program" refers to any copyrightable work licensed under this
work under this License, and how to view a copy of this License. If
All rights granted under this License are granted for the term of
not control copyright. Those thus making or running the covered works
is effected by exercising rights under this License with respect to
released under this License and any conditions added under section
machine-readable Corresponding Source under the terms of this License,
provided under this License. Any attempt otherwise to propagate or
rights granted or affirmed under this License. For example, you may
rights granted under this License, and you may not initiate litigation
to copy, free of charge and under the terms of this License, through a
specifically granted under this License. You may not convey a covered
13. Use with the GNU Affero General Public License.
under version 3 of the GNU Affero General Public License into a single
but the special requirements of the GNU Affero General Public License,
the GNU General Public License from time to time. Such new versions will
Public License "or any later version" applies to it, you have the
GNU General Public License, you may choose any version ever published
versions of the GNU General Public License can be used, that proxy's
